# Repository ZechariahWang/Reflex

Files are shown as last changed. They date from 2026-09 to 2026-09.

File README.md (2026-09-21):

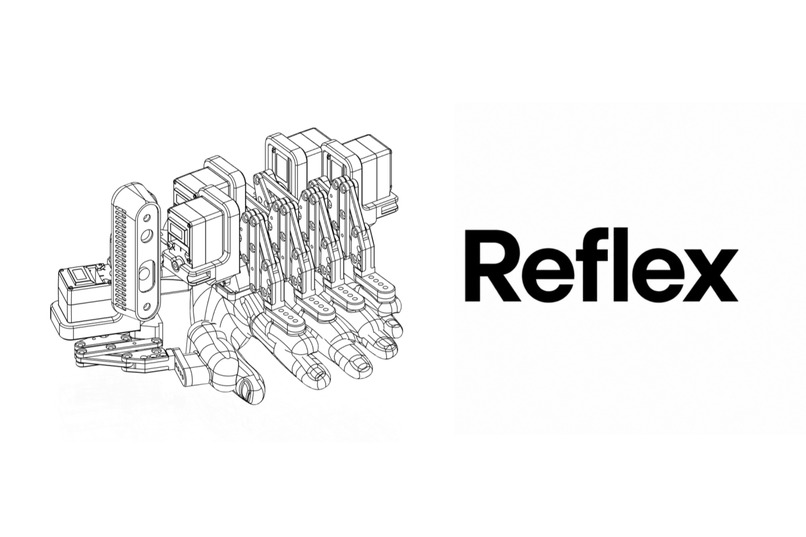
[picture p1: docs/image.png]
Reflex robotic exoskeleton hand


# Reflex

**Hack the North 2026 Finalist | Built in 36 hours**

[Devpost](https://devpost.com/software/reflex-e0jkih) |
[GitHub](https://github.com/ZechariahWang/Reflex)

**Usually, humans write skills for Claude. We wanted a hand where Claude could write skills for humans.**

Reflex is a wearable, 3D-printed gauntlet that gives AI control over five independently
actuated fingers. Built from the ground up at Hack the North 2026, it combines
programmable movements, hand-tracking teleoperation, and a fine-tuned SmolVLA policy
with a live digital twin. The same control interface drives the simulated hand
and the real servos.

The inspiration is hand-over-hand teaching: capture a physical motion, repeat it,
and explore how an AI can help guide it. Reflex is a hackathon prototype, not a
validated rehabilitation device.

Our vision is assistance with dexterous tasks: helping people with limited hand
mobility, guiding someone through a new skill, or supporting hands fatigued by
repetitive work. Those are the applications we want to explore, not established
clinical or workplace outcomes.

## What It Does

- **Agent-controlled movement:** an MCP server lets Claude inspect finger positions,
  command poses, and write, run, or edit named movement sequences.
- **Hand mirroring:** MediaPipe tracks a controller's hand through a webcam and
  translates its motion into finger commands after calibration.
- **Demonstration recording:** record and replay episodes from the console. The
  LeRobot integration connects demonstrations to SmolVLA training and inference.
- **Live digital twin:** a Three.js URDF view shows measured and commanded motion,
  IMU orientation, and tracked objects alongside RGB/depth feeds and motor telemetry.
- **Reusable skills:** rehearsed piano routines and taught movements live as
  readable Python files in [`movements/`](movements/README.md).

## The Piano Demo

One of our favorite demos paired Reflex with Claude to guide someone who had never
played piano through a tune, moving their fingers note by note. Claude runs the
finger routines through MCP while the console shows the commanded and measured
movement. It is a concrete example of the idea behind Reflex: an AI-authored skill
becoming a physical motion a person can experience.

## Built in 36 Hours

Reflex was built from the ground up in 36 hours at Hack the North, with Kevin Zhao,
Zechariah Wang, and Eric Liu. The project was selected as a Hack the North finalist.
See the [Devpost submission](https://devpost.com/software/reflex-e0jkih) for the
project story.

## Architecture

```text
Web console / Claude MCP
           |
     FastAPI backend
           |
        rosbridge <--- LeRobot / learned policy
           |
     ROS 2 hand HAL
       /         \
ros2_control   USB bus adapter
     |               |
   Gazebo       Feetech servos

Camera frames, IMU, and measured state flow back to the console.
```

Commands use five normalized finger positions in **thumb, index, middle, ring,
pinky** order: `0` is open and `1` is closed. Each finger has one controlled degree
of freedom. The HAL applies motion limits and hardware-specific control; agents
and learned policies use that same low-level interface.

## Tech Stack

| Area | Technology |
| --- | --- |
| Hardware | 3D-printed 5-DOF exoskeleton, Feetech STS3215 bus servos, USB servo adapter |
| Sensing | Gauntlet-mounted Intel RealSense D435i RGB/depth/IMU; iPhone + Record3D for an additional overhead or head-mounted view |
| Robot control | ROS 2 Humble, `ros2_control`, Gazebo Fortress, rosbridge |
| Backend | Python, FastAPI, `roslibpy`, OpenCV, MediaPipe |
| Console | Next.js, React, TypeScript, Three.js, React Three Fiber, `urdf-loader`, Zustand, Tailwind, shadcn |
| Agent interface | MCP tools for inspection, movement, and skill creation |
| Learning | LeRobot, SmolVLA, PyTorch |

## Quick Start

### Console Without Hardware

On Linux or WSL, install Python with `venv`, Node.js/npm, and the standard shell
utilities used by the launcher. From the repository root:

```bash
MOCK=1 ./application/dev.sh
```

Open **http://localhost:3000**. The launcher installs backend/frontend dependencies
on first run and starts FastAPI on port `8000` and Next.js on port `3000`.
Mock mode supplies synthetic hand state and camera feeds without ROS or hardware.

See the [console guide](application/README.md) for configuration and the
[API contract](application/CONTRACT.md) for topics and message formats.

### ROS Simulation

With ROS 2 Humble and Gazebo Fortress installed:

```bash
./physical_layer/build.sh
source physical_layer/ros2_ws/install/setup.bash
ros2 launch htn_launch sim.launch.py camera:=none
```

In a second terminal:

```bash
./application/dev.sh
```

Use `gui:=true` for the Gazebo window or `teleop:=false` to skip the finger-control
window. The simulator does not supply synthetic camera images: connect a real
camera for vision workflows, or use console mock mode.

Without a native Humble environment,
[`physical_layer/docker/run.sh`](physical_layer/docker/run.sh) provides a container
with the repository mounted. The host-side
[RealSense bridge](physical_layer/camera_bridge/realsense_bridge.py) can publish
camera data over rosbridge without a local ROS installation.

### Real Hand

After configuring servo IDs, calibration, and the serial device:

```bash
ros2 launch htn_launch hardware.launch.py serial_port:=/dev/ttyACM0
```

Physical dimensions, joint limits, and servo calibration live in
[`hand_params.yaml`](physical_layer/ros2_ws/src/htn_description/config/hand_params.yaml).
Read the [physical-layer notes](physical_layer/CLAUDE.md) before changing hardware settings.

The finger-control window uses `Q W E R T` to open the thumb through pinky and
`A S D F G` to close them. Release a key to hold position. Sliders and preset
gestures are available too. Foxglove can connect at `ws://localhost:8765`; import
the [hand layout](physical_layer/foxglove/htn_hand.json) for robot and camera views.

## Connect Claude

The MCP server is a separate client of the backend. Starting the console does
not automatically register it. On Linux/WSL, from the repository root:

```bash
python3 -m venv mcp_server/.venv
mcp_server/.venv/bin/pip install -r mcp_server/requirements.txt
claude mcp add htn-hand -- "$PWD/mcp_server/.venv/bin/python" "$PWD/mcp_server/server.py"
```

With the backend running, Claude can use `get_hand_state`, `move_hand`,
`list_skills`, `teach_skill`, `run_skill`, and `stop_skill`. For example:
"Read the hand state, then make a peace sign."

See the [MCP guide](mcp_server/README.md) for Claude Desktop, HTTP transport, and
remote backend configuration. MCP commands use the backend directly, so the
console's ARM switch does not gate them. HAL limits still apply; passive mode
disables motor torque and ignores motion commands.

## Learning From Demonstrations

The hand is packaged as a LeRobot robot. For the hackathon, demonstrations were
collected through MediaPipe hand tracking while controlling the simulated hand,
then used to fine-tune SmolVLA for grasp-related finger movements. This let us build
the training workflow without collecting demonstrations by driving a wearer's hand.

The recorded training run used 49 episodes, with 44 for training and five held out,
and completed 5,000 fine-tuning steps. See the
[training run notes](docs/notes/training/runs/RUN-20260920T093202Z/notes.md) for evaluation
results and limitations. The policy runs separately from ROS and communicates
through rosbridge; the RealSense also supplies depth for scene perception in the console.

See the [policy guide](policy/README.md) for Python requirements, dataset collection,
training, and inference commands. Held-out prediction accuracy measures how well
the model matches recorded actions; it does not by itself establish reliable
closed-loop grasping or general skill transfer.

## Repository Map

| Directory | Purpose |
| --- | --- |
| [`physical_layer/`](physical_layer/CLAUDE.md) | Robot description, ROS launch files, HAL, servo backends, teleop, camera bridges, and Docker setup |
| [`application/`](application/README.md) | FastAPI backend and live web console |
| [`mcp_server/`](mcp_server/README.md) | Claude-compatible hand-control and skill-management tools |
| [`movements/`](movements/README.md) | Rehearsed and agent-taught finger routines |
| [`policy/`](policy/README.md) | LeRobot integration, recording, training, and inference tooling |
| [`docs/`](docs/) | Designs, development notes, and demo instructions |

## What's Next

- Finish compliant, torque-on hand-guiding control. Existing torque-off backdrive
  mode is distinct from a tuned, soft hand-guiding controller.
- Expand the demonstration dataset and evaluate learned skills beyond their
  training examples.
- Explore how recorded motions and agent-authored skills can support physical
  skill practice and assistive tasks.

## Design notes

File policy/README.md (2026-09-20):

# policy

LeRobot side of the learned policy. Everything here runs on the GPU laptop and
reaches the hand through the rosbridge websocket of the ROS machine
(`ws://<ros-ip>:9090`). Design: `../docs/specs/policy-link-design.md`.

`lerobot_robot_exo_hand` is the hand as a LeRobot `Robot` (`--robot.type=exo_hand`).

## Setup

Python >= 3.12 (a requirement of `lerobot`). No ROS.

```bash
cd policy
uv venv --python 3.12 && source .venv/bin/activate
uv pip install -e ".[dev]" "lerobot[smolvla,async,training]==0.6.1"   # async = gRPC for the inference loop, training = lerobot-train
python -m pytest            # no rosbridge needed
```

## Smoke check

With `sim.launch.py` or `hardware.launch.py` running on the ROS machine and the
camera plugged in (the sim has no simulated camera):

```bash
python -m lerobot_robot_exo_hand.exo_hand --host <ros-ip>
```

It prints one observation (the state and the shapes of `camera1`, the head
iPhone, and `camera2`, the wrist RealSense), closes the hand, opens it again, and
fails if `/hand/state` does not follow. With no phone: `--head-topic ""`, and
`--robot.head_topic=""` in the commands below.

## The instruction

One constant string, in every episode and at inference, character for character:

    grasp and put down objects, make a peace sign at a person

It is the default of the console's Task field. The model sees the same words in every sample, so
they tell it nothing: WHICH of the two it does, and when, it learns from the cameras in the
episodes. A different string at inference is an input it was never trained on. So the data has to
tell the two apart:

- grasp episodes with people in the background (or every person in view means "peace sign");
- peace sign episodes with one clear cue: the hand up, palm away, a person close and centred;
- idle episodes: a person in view, or an object out of reach, and the hand does nothing;
- every grasp episode is the whole cycle: approach, grasp, hold, put down, release;
- about as many episodes of the one as of the other.

## Data collection: mirror teleop (torque on)

Design: `../docs/specs/mirror-teleop-design.md`. A second person (the controller)
closes a hand in front of a browser webcam, the web console turns it into
`/hand/command`, and the hand moves with the torque on. `exo_hand_command` records
the last `/hand/command` as the action (the measured `/hand/state` until the first
command); the observation state is `/hand/state`. It works with any command source
(mirror, sliders, keys), and refuses a HAL in passive mode. `--robot.passive=true`
stops the robot from publishing each command a second time. No `label.py` step.

In the web console: ARM, Mirror on, calibrate (open hand, fist), match the hand
until the mode is `following`. Nobody arms the sliders in another tab. Then:

```bash
lerobot-record \
    --robot.type=exo_hand --robot.host=<ros-ip> --robot.id=exo --robot.passive=true \
    --teleop.type=exo_hand_command --teleop.host=<ros-ip> --teleop.id=exo \
    --dataset.repo_id=<user>/exo_grasp --dataset.push_to_hub=false \
    --dataset.root=policy/datasets/exo_grasp \
    --dataset.single_task="grasp and put down objects, make a peace sign at a person" \
    --dataset.fps=30 --dataset.num_episodes=50 \
    --dataset.episode_time_s=20 --dataset.reset_time_s=5
```

Right arrow = save the episode, left arrow = record it again, Esc = stop (the keys
may not work on Wayland; `episode_time_s` is the upper limit then).

## Data collection from the web console

The Episodes bar of the console (under the 3D hand) records without LeRobot on the ROS machine:
type a dataset name and the task, **Record**, move the hand (mirror, sliders, keys), **Save** or
**Discard**; **Replay** plays an episode back on the hand and in the camera panels. The episodes are
in `policy/datasets/console/<name>/` in the console's own format
(`application/CONTRACT.md`, Episodes). On the machine that trains:

```bash
python -m lerobot_robot_exo_hand.from_console --root policy/datasets/console/exo_grasp
```

writes `policy/datasets/exo_grasp`, a LeRobot dataset with the same columns as `lerobot-record`
below (`observation.state`, `action` = the last command, `camera1`, `camera2`). Not run against
lerobot yet when it was written: check the first conversion with `lerobot-dataset-viz` or the
replay below.

## Replay of a LeRobot dataset

```bash
python -m lerobot_robot_exo_hand.replay --root policy/datasets/exo_grasp --episode 0 --host <ros-ip>
```

Plays one episode back through rosbridge at the fps it was recorded with: `action` goes to
`/hand/command` (the hand of the sim, or the real one, does what it was told), and the two camera
images go to `/head_camera/color/image_raw/compressed` and `/camera/color/image_raw/compressed`,
so the web console and Foxglove show what the cameras saw next to the moving hand. For that the ROS
side must have NO camera of its own running: `ros2 launch htn_launch sim.launch.py camera:=none`.
With a live camera pass `--no-images` (the hand only). `--what state` sends the measured
`observation.state` instead of the action (what the hand did, not what it was told),
`--speed 0.5` is half speed, `--loop` repeats until Ctrl-C. It commands the hand: on the real one,
clear its surroundings first. The episode is decoded before the first frame goes out, so a slow
video decode is not part of the timing.

## Data collection: backdrive (closed for these servos)

Design: `../docs/specs/data-collection-design.md`. The HAL is in its torque-off
mode, a person moves the fingers, and the encoder positions are the actions.
`exo_hand_leader` reads them from `/hand/state`; `--robot.passive=true` stops
the adapter from publishing them as commands.

First put the HAL in that mode, on the ROS machine: start it with
`ros2 launch htn_launch hardware.launch.py passive:=true`, or switch a running
one with the Backdrive button of the control window / web console, or
`ros2 service call /hand/set_passive std_srvs/srv/SetBool '{data: true}'`.
`/hand/passive` (latched Bool) tells which mode it is in. With the torque on the
fingers do not move and every label is constant, so `exo_hand_leader` refuses to
record unless `/hand/passive` is true (`--teleop.require_passive=false` for a
recording where something else commands the hand). Afterwards switch it off the
same way (`data: false`): the hand then holds the pose the fingers are in.

Then run from the repo root:

```bash
lerobot-record \
    --robot.type=exo_hand --robot.host=<ros-ip> --robot.id=exo --robot.passive=true \
    --teleop.type=exo_hand_leader --teleop.host=<ros-ip> --teleop.id=exo \
    --dataset.repo_id=<user>/exo_grasp_raw --dataset.push_to_hub=false \
    --dataset.root=policy/datasets/exo_grasp_raw \
    --dataset.single_task="grasp and put down objects, make a peace sign at a person" \
    --dataset.fps=15 --dataset.num_episodes=50 \
    --dataset.episode_time_s=20 --dataset.reset_time_s=5

python -m lerobot_robot_exo_hand.label --root=policy/datasets/exo_grasp_raw --k=3 --gain=0.2
```

The second command writes `policy/datasets/exo_grasp_raw_k3_g20`, the dataset
to train on: `action[t] = min(1, state[t+k] * (1 + gain))`. The raw dataset
does not change, so `k` and `gain` can change with no new recording.

`policy/datasets/` is ignored by git and is not a cache: make a copy outside
the repo after each session.

## Training

`lerobot-train` does it; there is no training code of ours. A rental of a Lambda GPU runs it
with no person at the keyboard (next section). By hand, on a machine with a GPU: the Setup
above, then

```bash
lerobot-train \
    --policy.path=lerobot/smolvla_base --policy.device=cuda --policy.push_to_hub=false \
    --dataset.repo_id=<user>/exo_grasp_raw_k3_g20 --dataset.root=<path>/exo_grasp_raw_k3_g20 \
    --batch_size=64 --steps=20000 --save_freq=5000 \
    --output_dir=outputs/train/exo_grasp --wandb.enable=false
```

The checkpoint for the inference loop is
`outputs/train/exo_grasp/checkpoints/last/pretrained_model` (~1.3 GB with the
training state). Copy it off a cloud instance before termination.

Checked on 2026-09-19 with a dry run on a CPU (10 steps, batch 2, the
150-frame test recording): the 5-value state and action need no option and no
model change, the loss goes down, and the checkpoint gives a `(1, 5)` action
from a 5-value state and one `camera2` image. `batch_size`, `steps` and the
`cuda` device are not run. The checkpoint keeps the input list of
`smolvla_base` in its `config.json` (a 6-value state, `camera1`..`camera3`);
the model pads the state to 32 values and skips the cameras that are not
there, so this had no effect in the dry run.

If the log says that `torchcodec` cannot load `libavutil`, lerobot decodes the
video with `pyav`. It works, and it is slower: install an FFmpeg that
`torchcodec` supports on the training machine.

## Training on a rented Lambda GPU

Design: `../docs/specs/lambda-training-design.md`. `lambda/launch.sh` rents one instance, uploads
`policy/`, one dataset, the `exo-trainer` skill and `docs/notes/training/`, and starts Claude Code
(Fable 5.1) there. The agent runs the variants of `docs/notes/training/plan.md`, evaluates each
checkpoint on held-out episodes (`heldout.py`), writes `docs/notes/training/runs/RUN-<UTC>/` and
ends the rental. `lambda/watchdog.sh` on the laptop pulls `policy/outputs/`, `policy/logs/` and the
run notes every 5 minutes and terminates the instance: 30 minutes after the last sign of life, at
`LAMBDA_MAX_HOURS`, or when the agent asks. **Keep the laptop awake and online for the whole
rental: nothing else stops the billing.**

```bash
cp policy/lambda/.env.example policy/lambda/.env   # the keys, the GPU type, LAMBDA_DATASET, the cap
policy/lambda/check_key.sh
policy/lambda/launch.sh --dry-run          # the confirm screen and the capacity, no launch
policy/lambda/launch.sh --smoke-scripts    # ~10 min, no agent: 50 steps on a fake dataset
policy/lambda/launch.sh --smoke            # the agent, two 50-step variants on the fake dataset
policy/lambda/launch.sh                    # the rental of plan.md; then: tmux attach -t htn-train
policy/lambda/check_instance.sh            # what bills now
policy/lambda/terminate.sh                 # stop it by hand
```

A smoke run is good if a `pretrained_model` folder and a `results.jsonl` are on the laptop and
`check_instance.sh` shows no instance. Several recording sessions: merge them into one dataset
before a rental. Delete an episode only with `lerobot-edit-dataset`, never by hand: it numbers the
episodes again. The checkpoints come home without `training_state/` (~1 GB each), so a run does not
resume on another rental. Revoke the `claude setup-token` token after the hackathon.

Tests of the scripts, with no instance and no key:

```bash
for t in policy/lambda/tests/test_*.sh; do bash "$t"; done
```

## Inference loop

Two processes on the GPU laptop. The server stays on localhost; only rosbridge
crosses the network. The ROS side runs first: rosbridge, the two cameras, the HAL.

```bash
cp .env.example .env     # once: POLICY_CHECKPOINT = the pretrained_model folder of a checkpoint, ROS_HOST
./run_policy.sh          # the policy server, then the robot client. Ctrl+C stops both
```

`run_policy.sh` refuses a checkpoint folder with no `model.safetensors` and a `POLICY_PORT` that is
already in use (any listener there passes the wait for the server, and the client then talks to the
wrong one), drops the `PYTHONPATH` of a shell that has sourced ROS (its Python 3.10 packages break the
import of lerobot), and gives the client the instruction above. With no phone on the forehead,
`POLICY_HEAD_TOPIC=` (set, and empty) in `.env` runs on the wrist camera only: a model that was
trained with both cameras does worse like that. The hand does not move yet: the policy waits for the **Policy** switch of the web
console (command block, armed). The switch is the latched `/policy/enabled`; while it is off the
adapter drops every action, and the step to off opens the hand once. `/policy/active` is the
heartbeat that the console shows as offline / ready / running. `POLICY_GATE=0` in `.env` is a run
with no console: the policy moves the hand from its first action. The switch is a convenience, not
an emergency stop: that is Ctrl+C here, and the limits of the HAL. The same by hand, in two terminals:

```bash
python -m lerobot.async_inference.policy_server --port=8080

python -m lerobot.async_inference.robot_client \
    --robot.type=exo_hand --robot.host=<ros-ip> --robot.id=exo \
    --server_address=localhost:8080 \
    --policy_type=smolvla --pretrained_name_or_path=<checkpoint> \
    --policy_device=cuda \
    --task="grasp and put down objects, make a peace sign at a person" \
    --fps=30 --actions_per_chunk=20 --chunk_size_threshold=0.7 \
    --debug_visualize_queue_size=True
```

Measured on the RTX 4050 laptop (2026-09-20, the 3000-step checkpoint): an inference takes 0.15 .. 1.2 s.
`POLICY_ACTIONS_PER_CHUNK` times the tick must be longer than that, or the hand waits between chunks:
20 actions are 0.67 s at 30 fps, too short there; 50 (the whole chunk of the model, 1.67 s) is not.

A client that dies without closing its websocket leaves rosbridge queueing camera images for it:
its memory grew ~3 MB/s, every client saw gaps of up to 0.7 s, and the robot client logged `no data
from rosbridge within 0.3 s`. Seen once, after two such clients; a fresh rosbridge cured it.

`--fps` (`POLICY_FPS`) is the rate of `send_action()`, and it is the tick rate of the dataset: 30
for a dataset of the web console, the `--dataset.fps` of a `lerobot-record` one. One action of the
model is one tick, so a lower rate plays every movement too slowly. The cameras deliver 15 fps: two
ticks see the same picture, as in the recording. The HAL must
be active: `ExoHand` raises if it is passive, because a passive HAL ignores
every command. To stop the
policy and take the hand back with teleop, stop the client: a running policy
overrides every other publisher on `/hand/command`.

The client of lerobot 0.6.1 has no `rename_map` option, and the server replaces
the map of the checkpoint with an empty one. The adapter therefore names its
camera `camera2`, an image key of `smolvla_base`, and no map is used anywhere.

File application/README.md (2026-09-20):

# application/ - hand simulator console

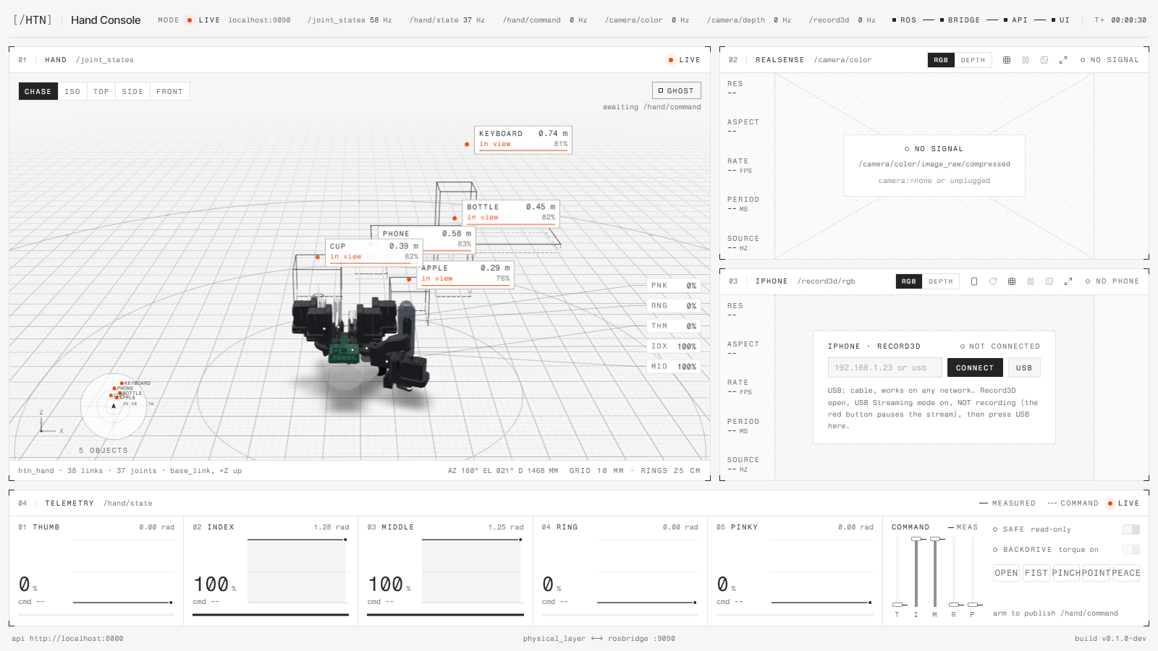
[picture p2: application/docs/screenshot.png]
Hand Console


A one-screen web console for the exoskeleton hand: a three.js viewport of the hand
moving live with a map of the objects around it (detected in the wrist camera, placed with its
depth, faded out when they are not detected any more), a RealSense panel that switches between RGB and
colorized depth, an iPhone (head camera) panel,
and an ARM-gated command block. It only consumes ROS topics from `physical_layer/`,
so it looks the same for the Gazebo sim and the real hardware.
```
physical_layer (ROS 2) --rosbridge ws :9090--> backend (FastAPI :8000) --ws/http--> frontend (Next.js :3000)
```

- `backend/`  - FastAPI + roslibpy. The only thing that talks to ROS. Caches the latest
  value of every topic, colorizes depth, serves `/api/health`, `/api/urdf`, `/ws/state`,
  `/ws/camera/realsense/{color,depth}`, `/ws/camera/iphone/color`. Reconnects to rosbridge forever.
  The iPhone is a ROS camera too (`/head_camera`, started with `head_camera:=iphone`).
- `frontend/` - Next.js, Tailwind, shadcn/ui, motion, three.js (@react-three/fiber, urdf-loader).
- `CONTRACT.md` - every API shape, topic and design rule. Read it before changing either side.

## Run

```bash
# terminal 1 - the ROS side (starts rosbridge on :9090; hardware.launch.py works the same)
ros2 launch htn_launch sim.launch.py

# terminal 2 - backend + frontend, Ctrl-C stops both
./dev.sh                # then open http://localhost:3000
MOCK=1 ./dev.sh         # no ROS at all: synthetic hand, color and depth
```

`dev.sh` creates `backend/.venv` and `frontend/node_modules` on first run. The object
detector is optional: `backend/.venv/bin/pip install -r backend/requirements-detect.txt
--extra-index-url https://download.pytorch.org/whl/cpu` (CPU torch, ~300 MB); without it the
map stays empty in live mode and the backend says so once. Start order does
not matter: with ROS down the console shows OFFLINE / NO SIGNAL and recovers on its own.

| env | default | |
|---|---|---|
| `MOCK` | `0` | `1` = synthesize everything |
| `MOCK_OBJECTS` | `0` | `1` = live ROS, synthetic objects around the hand (a sim has no camera) |
| `REALSENSE_ROTATION` | `270` | degrees clockwise the RealSense picture is turned on the page and for the object detector (the camera sits portrait on the hand); `0` = as sent |
| `DETECT_MODEL` | `yolov8n.pt` | Ultralytics model that finds the objects around the hand in the RealSense image; needs `backend/requirements-detect.txt`, `""` turns it off |
| `DETECT_HZ` / `DETECT_THREADS` | `4` / `2` | detector passes per second at most, and its torch threads (it shares the CPU with the sim and the browser) |
| `ROSBRIDGE_HOST` / `ROSBRIDGE_PORT` | `localhost` / `9090` | where rosbridge listens |
| `BACKEND_PORT` / `FRONTEND_PORT` | `8000` / `3000` | dev.sh ports |
| `BACKEND_HOST` | `127.0.0.1` | dev.sh bind address of the API; `0.0.0.0` from a container or for another machine |
| `DEPTH_MIN_MM` / `DEPTH_MAX_MM` | `150` / `2000` | depth colormap range |
| `CORS_ORIGINS` | `http://localhost:3000,http://127.0.0.1:3000` | pages allowed to call the API and open its websockets |

Viewing from another machine needs `CORS_ORIGINS=http://<host>:3000`, `NEXT_PUBLIC_BACKEND_URL=http://<host>:8000`
and `BACKEND_HOST=0.0.0.0`.

Commands only leave the page while the ARM switch is on; it disarms itself when ROS drops.

Checks: `backend/.venv/bin/pytest` (needs `requirements-dev.txt`); in `frontend/`: `npx tsc --noEmit && npx eslint . && npm run build`.

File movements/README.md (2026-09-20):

# movements

Pre-written movements of the hand, played from the web console (Episodes bar -> the Movement
dropdown -> Play). One Python file = one movement; the backend lists every `*.py` here whose name
does not start with `_`. Add a file, reload the page, it is in the dropdown.

A movement file has:

```python
TITLE = "Hot cross buns"             # the name in the dropdown
DESCRIPTION = "one line, optional"

def steps():
    """The movement: a list of (pose, seconds). The pose is sent to /hand/command; the next one
    is sent when `seconds` have passed AND the hand has arrived at this one. A pose is 5 values
    in the order thumb, index, middle, ring, pinky, 0 = open .. 1 = closed."""
    return [([0, 0, 0, 0, 0], 0.5), ([0, 1, 1, 0, 0], 1.0)]
```

A step never starts before the last one has arrived: every finger measured within 0.04 of the
pose that was sent. So `seconds` is the shortest a step takes, and slow motors stretch the tempo
instead of cutting strokes short. A finger that cannot arrive (something is in its way, the torque
is off) holds the movement for 3 s, then it goes on; the status counts those steps (`not_arrived`).

Rules the backend checks: at most 2000 steps, each 0 < seconds <= 30, values are clamped to 0..1.
The HAL still rate-limits every move (`max_speed` 4.0 of the travel per second: a full close takes ~0.3 s, a stroke of depth d about d / 4 + 0.07 s) and the contact stop
still applies: a movement cannot go faster or push harder than a slider can. A movement can play
while an episode is being recorded (that is a way to record demonstrations), not during a replay.

Try one without the console: `python3 movements/hot_cross_buns.py` prints its steps.

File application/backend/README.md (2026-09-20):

# backend

FastAPI bridge between rosbridge (`ws://localhost:9090`) and the browser. API: `../CONTRACT.md`.

```bash
python3 -m venv .venv && .venv/bin/pip install -r requirements-dev.txt   # setup
.venv/bin/uvicorn app.main:app --port 8000                               # run (ROS may be down; it reconnects forever)
MOCK=1 .venv/bin/uvicorn app.main:app --port 8000                        # mock mode: no ROS, synthetic hand + cameras
.venv/bin/python -m pytest -q                                            # tests
```

Env: `ROSBRIDGE_HOST` (localhost), `ROSBRIDGE_PORT` (9090), `MOCK` (0), `CORS_ORIGINS` (http://localhost:3000,http://127.0.0.1:3000;
comma-separated), `DEPTH_MIN_MM` (150), `DEPTH_MAX_MM` (2000), `MIRROR_*` (mirror teleop tuning, see `../CONTRACT.md`).

iPhone: a ROS camera like the RealSense (`/head_camera/color/image_raw/compressed`, from `camera.launch.py head_camera:=iphone`);
the backend passes its JPEGs through. The phone itself (Record3D, USB) belongs to the ROS node. No phone around? `MOCK=1`.

Mirror teleop: `app/mirror/` tracks the controller's webcam frames from `/ws/mirror` with MediaPipe (`models/hand_landmarker.task`, Google's
pretrained float16 model, in the repo so nothing downloads at run time). The pinned numpy needs Python <= 3.13 for the venv.

`mock/hand.urdf` is generated from `htn_description/urdf/hand.urdf.xacro`; regenerate it if the xacro changes.

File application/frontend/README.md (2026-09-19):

# frontend - HTN hand console

Next.js (App Router) + Tailwind v4 + shadcn/ui + motion + three.js (`@react-three/fiber`, `drei`, `urdf-loader`).
One screen: hand viewport, color + depth camera views, telemetry strip. Architecture and API: `../CONTRACT.md`.

```bash
cp .env.example .env.local   # NEXT_PUBLIC_BACKEND_URL, default http://localhost:8000
npm install
npm run dev                  # http://localhost:3000 (start ../backend first; MOCK=1 needs no ROS)
```

Shared code: `src/lib/{config,types,sim-store}.ts`, `src/hooks/use-camera-stream.ts`, `src/components/console/panel.tsx`; design tokens and the `label-micro` / `num` / `hairline-frame` / `bg-dot-grid` utilities live in `src/app/globals.css`.

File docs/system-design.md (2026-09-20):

# System design

Device layout, ROS layout and learned finger control for the exoskeleton hand.
Status: design only, the autonomous part is not implemented. Date of the
discussion: 2026-09-19.

## Device layout

```
        on the wearer                                  on a table
+--------------------------------+            +---------------------------+
| hand                           |            | GPU laptop (8 GB VRAM)    |
|   servos <- USB-C motor driver |            |   LeRobot policy_server   |
|   wrist camera (RGB + depth)   |            |   SmolVLA                 |
|        | USB          | USB    |            |   RobotClient + ExoHand   |
| wearable ROS machine           |  5 GHz     |   no ROS                  |
|   (Pi 5 or small laptop)       |  WiFi      |                           |
|   ROS 2 Humble, rosbridge      | <--ws:9090-|                           |
+--------------------------------+            +---------------------------+
```

- **Hand:** 5 servos behind a USB-C motor driver, and a wrist camera with depth.
  Both connect to the wearable machine over USB.
- **Wearable ROS machine:** runs all ROS nodes. The wearer carries it. It has
  no GPU work, no `lerobot` and no torch.
- **GPU laptop:** runs all the LeRobot parts: `policy_server`, `RobotClient`
  and the `ExoHand` adapter (`lerobot-record` also, during data collection).
  It stays off the body. It needs no ROS, only `roslibpy`.
- **Link:** 5 GHz WiFi hotspot. Bluetooth is too slow for video. An Ethernet
  cable is an option only when the wearer does not move around.
- **Viewing:** a third device can open Foxglove on
  `ws://<wearable-ip>:8765`. It needs no ROS.

Only the rosbridge WebSocket (JSON: `/hand/state`, JPEG frames in, and
`/hand/command` out) and the Foxglove WebSocket cross the network. No DDS
traffic crosses it, so the ROS 2 over WiFi problems (multicast discovery,
fragmented image messages) do not apply. gRPC between `RobotClient` and
`policy_server` stays on localhost of the GPU laptop. See
`specs/policy-link-design.md`.

rosbridge has no authentication: any device on the network can publish
`/hand/command`. Use an own router, a hotspot or a cable, not the venue WiFi.

## ROS layout (wearable machine)

```
camera node --/camera/... images--+
                                  v
                             rosbridge  <--ws:9090-->  ExoHand adapter (GPU laptop)
                                  |  ^
                   /hand/command  v  |  /hand/state
teleop_gui --/hand/command-->    HAL  --USB--> motor driver --> servos
                                  |
                                  +--/hand/state, /joint_states--> foxglove_bridge
```

- `hardware.launch.py` starts `robot_state_publisher`, the HAL (feetech
  backend), `teleop_gui`, the camera node, `foxglove_bridge` and
  `rosbridge_websocket`. The policy link adds no node to this machine.
- The contract does not change: anything that moves the hand publishes
  `/hand/command` (5 values, `0` = open, `1` = closed) and reads `/hand/state`.
  The policy is one more publisher, the same as teleop. The topic is shared
  and the last message wins, so a publisher sends only when it has something
  new; the policy adapter has a deadband for this.
- The HAL clamps and rate-limits (`max_speed`) each command before it reaches
  the servos. This stays below the policy.
- The image topics are also the source for dataset recording and for Foxglove,
  so video and `/hand/state` have timestamps from one clock.

### Wearable machine: Pi 5 or small laptop

| | Pi 5 | Small x86 laptop |
|---|---|---|
| ROS 2 Humble | Needs a container. Ubuntu 22.04 does not boot on a Pi 5. Use distrobox with `ubuntu:22.04` on Raspberry Pi OS or Ubuntu 24.04. | Native, or the same distrobox setup as the dev machine |
| Device access in distrobox | Create the box with `--additional-flags "--group-add keep-groups"` (or `--root`) for `/dev/ttyACM0` and the camera | Same |
| Teleop window | `teleop_gui` needs a display and a keyboard | Built in |
| Power | 5 V / 5 A supply, plus 1-2 W for the camera | Own battery |
| Video encode | No hardware encoder; the `/compressed` topics are JPEG on the CPU, and rosbridge adds base64 per client. Measure the load early. | - |

Start at boot on a Pi: a systemd service that runs
`distrobox enter humble -- <launch command>`. Test it early.

## Policy

**SmolVLA** (0.45B parameters, Apache 2.0, part of
[LeRobot](https://github.com/huggingface/lerobot)), fine-tuned with one constant
instruction.

- **Task:** close when the wearer reaches for an object, hold during transport,
  release when the wearer puts the object down. The wearer cannot move their
  fingers. The servos cannot be backdriven: a torque-off mode exists in the HAL,
  but the gear friction makes the fingers too stiff to move by hand
  (`specs/data-collection-design.md`, Backdrive result).
- **Input:** wrist RGB and depth, and the 5 values of `/hand/state`.
  **Output:** 5 targets for `/hand/command`.
- Inference needs ~2 GB of VRAM. The constant instruction makes the language
  input irrelevant; the reason to use a VLA is the pretrained vision.
- Fallback if SmolVLA generalizes poorly: GR00T N1.6. π0 and π0.5 do not fit.

| Model | Inference VRAM | Fine-tune VRAM |
|---|---|---|
| SmolVLA | ~2 GB | 10-24 GB |
| GR00T N1.6 | ~6 GB | 24 GB+ |
| π0 / π0.5 | 8 GB+ | 22.5 GB+ (LoRA) |

### Inputs

- State and action have 5 values each. SmolVLA pads them to its internal size.
- `smolvla_base` declares three image slots, `observation.images.camera1`,
  `camera2`, `camera3` (top, wrist, side in the pretraining data). Map the
  dataset keys to the slots with `--rename_map`, and mask unused slots with
  `--policy.empty_cameras=N`. Put the wrist RGB in `camera2`.
- Async inference in lerobot 0.6.1 ignores `rename_map`, so the adapter names
  its camera `camera2` directly and no map is used, see
  `specs/policy-link-design.md`.
- **Depth:** record it as a second video stream (color map) and map it to a
  camera slot. The vision encoder has not seen depth images, so unfreeze it for
  that run (`freeze_vision_encoder=false`, `train_expert_only=false`). Option if
  depth does not help as an image: add the median center depth to the state
  vector.

### Inference link

Uses [LeRobot asynchronous inference](https://huggingface.co/docs/lerobot/en/async).
The server computes the next chunk of actions while the client executes the
current one.

- GPU laptop:
  `python -m lerobot.async_inference.policy_server --host=0.0.0.0 --port=8080`.
  The server starts empty; the client names the policy and the checkpoint at
  the first connection.
- Also on the GPU laptop: a `RobotClient` that wraps one small LeRobot `Robot`
  subclass for the hand (`ExoHand`). It reaches the ROS topics through
  rosbridge with `roslibpy`. `get_observation()` returns the latest frame and
  `/hand/state`; `send_action()` publishes to `/hand/command`. The action
  queue is thus off the robot: each command crosses WiFi.
- `lerobot-record` uses the same `Robot` class, so recording and inference
  share keys and camera order.
- Start with `actions_per_chunk` = 10-20 and `chunk_size_threshold` = 0.7 for a
  short reaction time. Check the queue with `--debug_visualize_queue_size=True`.

| Step | Time |
|---|---|
| WiFi, one direction | 2-10 ms, spikes to 50 ms or more |
| Frame age at `get_observation()` | up to 66 ms at 15 fps, plus transit |
| SmolVLA inference | 100-200 ms |

## Training

- Cloud GPU on Lambda. An A10 (24 GB) is sufficient for the default fine-tune;
  use an A100 for the run with the unfrozen vision encoder.
- How a rental runs (launch, watchdog on the laptop, agent on the instance,
  held-out evaluation): `specs/lambda-training-design.md`.
- Lambda deletes the instance storage at termination. The watchdog on the
  laptop pulls the checkpoints with `rsync`; nothing goes to Hugging Face.
- Dataset storage: local files only. The dataset contains video of people; it
  goes from the laptop to the instance by `rsync` and nowhere else.
- 20,000 steps take ~4 hours on an A100.
- Train three versions and compare them on held-out objects:
  1. RGB only, frozen vision encoder (default)
  2. RGB and depth, frozen
  3. RGB and depth, unfrozen

## Safety

These stay in the HAL, below the policy and the network. The motor driver has
no firmware of ours, so the HAL is the lowest layer that we control:

- Clamp and rate limit (exists in the HAL).
- Hard limit on force or current.
- Link loss: the HAL keeps the last target with no time limit, so the hand
  finishes its last commanded move and holds. Hold is the chosen action (an
  open drops the object at each WiFi dropout), so the HAL needs no watchdog.
  The adapter stops the client when its data is old.
- An emergency open that the wearer can always reach.

## Open questions

1. **Where the `RobotClient` runs.** Closed, see
   `specs/policy-link-design.md`: on the GPU laptop, through rosbridge. No
   process imports both `rclpy` and `lerobot`, and `htn_auto` is removed.
2. **Depth camera model.** The object is 5-20 cm from a wrist camera at the
   moment of the grasp. A RealSense D435 cannot measure below ~28 cm; a D405
   operates from ~7 cm. On a Pi, `librealsense` needs a source build.
3. **Release signal.** A learned release is a risk (dropped object or trapped
   hand). Recommended for the first version: learned close, explicit release
   input from the wearer (button, voice, or IMU gesture).
4. **Wearable machine.** Pi 5 or small laptop, see the table above.
5. **Wrist IMU.** It gives the "arm stopped" cue directly and helps most with
   the release.
6. **Motor driver protocol.** Closed, see `specs/feetech-hal-design.md`: Feetech ST
   servos on a USB bus adapter, position feedback, no command timeout. Original question: The `SerialBackend` in the HAL speaks an ASCII
   protocol (`S ...` / `P ...` lines) made for our own firmware. A driver board
   has its own protocol, so the HAL needs a backend for it. Check also whether
   the driver has a command timeout and position feedback; if it has no
   timeout, the watchdog must be in the HAL.
7. **Command arbitration.** `/hand/command` is shared and the last message
   wins. A policy that streams at 15-30 Hz overrides teleop and the web
   console while it runs; the only takeover is to stop the client.

## Alternatives considered

- **Pi with no ROS** (MJPEG stream plus the serial port over TCP, all ROS on
  the GPU machine). Simplest, but it puts ROS and the GPU on one machine.
- **ROS nodes on two machines.** ROS 2 over WiFi is unreliable (discovery,
  large messages).
- **`RobotClient` on the wearable machine** (gRPC across WiFi, the action
  queue on the robot). The queue drains through a short dropout, but
  `lerobot` and torch go onto the wearable machine, and one process needs
  both `rclpy` (Python 3.10) and `lerobot`.
- **One laptop for everything.** Rejected: the wearer must not carry the GPU.
- **ACT.** Not used, also not as a baseline: it has no pretrained vision, and
  SmolVLA is the only model that is trained.

## Links

- [LeRobot repository](https://github.com/huggingface/lerobot)
- [Async inference docs](https://huggingface.co/docs/lerobot/en/async),
  [source](https://github.com/huggingface/lerobot/tree/main/src/lerobot/async_inference)
- [SmolVLA docs](https://huggingface.co/docs/lerobot/en/smolvla),
  [base weights](https://huggingface.co/lerobot/smolvla_base)
- [Rename map and empty cameras](https://huggingface.co/docs/lerobot/rename_map)
- [rosbridge protocol](https://github.com/RobotWebTools/rosbridge_suite/blob/ros2/ROSBRIDGE_PROTOCOL.md),
  [roslibpy](https://roslibpy.readthedocs.io/)
- [ACT paper](https://arxiv.org/abs/2304.13705)

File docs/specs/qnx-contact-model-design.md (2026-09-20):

# QNX track: a learned contact detector on a Raspberry Pi

Status: proposal from the discussion of 2026-09-20. Nothing is built and nothing here is tested
on QNX. The open questions at the end are not decided.

## The track

Hard requirements: the project uses QNX OS, and it includes one of the open-source AI modules
of https://oss.qnx.com. Judging: is it a "cannot-fail" embedded application, does it need
real time or reliability, is the AI use interesting, and does it run on the embedded hardware
or a QNX VM (not in the cloud).

The SmolVLA policy runs on the GPU laptop, so it does not count. Something with AI has to run
on the QNX machine itself.

## The idea

A Raspberry Pi 4 with QNX 8.0 runs a small model that says, per finger, "this finger meets
resistance". It is a learned version of the contact stop in `hal/contact.py`.

Why this and not a vision model: the contact stop IS the safety decision of the hand (it
protects the linkage and the wearer's fingers, and it sets the grip force), it needs the 50 Hz
loop, and it must keep working when the laptop or the policy dies. That is the story the judges
ask for.

### What the model can do better than the threshold

The detector of today sums the motor current above `blocked_current` (100 mA) and blocks at
`blocked_excess` (100). One threshold for every position and speed:

- a free start of the middle finger already summed to 34;
- near a linkage bind the leverage changes, so the current for the same force depends on where
  the finger is (ring and pinky are within a few degrees of a bind, `next-work.md`);
- it cannot be early: it waits for the sum.

A model that sees position and velocity next to the current can learn both.

### Model

- Input: the last ~10 HAL cycles (0.2 s) of one finger: current (mA), position, velocity, push
  direction. One model for all five fingers, run once per finger.
- Output: probability of contact.
- A small 1D-CNN or MLP: far below 1 ms on a Pi 4.
- Trained on the laptop (Keras), converted to `.tflite`, run on QNX with
  `python3-tflite-runtime`.

### Safety rule

`blocked = threshold detector OR model`. The model can only stop a finger earlier; it can never
cancel a stop of the threshold. Torque limits, clamps and the threshold stay hard-coded below
it ("Safety limits ... belong in the HAL and the servo registers, below any learned policy").

## Two ways to build it

1. **Advisory (no hardware risk).** The HAL stays on the laptop. A relay node (~30 lines) sends
   `/hand/current`, `/hand/state` and `/hand/command` to the Pi on UDP, the Pi sends the model's
   verdict back, the console shows it next to `/hand/blocked`. The verdict does NOT stop the
   hand: a network link in the safety path is worse than what there is now. Qualifies, but the
   Pi is a side process and a judge can see that.
2. **The HAL on the Pi (the full story).** The Pi owns the servo bus and runs the 50 Hz loop,
   the threshold, the model and a watchdog that holds the pose when the laptop goes silent. The
   laptop only sends `/hand/command`. `hal/` is ~430 lines and needs only `rclpy`, `std_msgs`,
   `std_srvs`, `sensor_msgs` and `pyserial`.

Recommended order: 1 first, then 2 if the USB adapter test below passes.

## What is on oss.qnx.com

From the dashboard's API (`/packages?package_name=...&arch_id=aarch64&latest_only=1` on the
`API_URL` in the page source), 2026-09-20. Prebuilt `apk` packages unless noted; targets are
Raspberry Pi 4 and 5.

| Module | Packages | QNX | Python |
|---|---|---|---|
| TensorFlow Lite | `tflite-runtime`, `python3-tflite-runtime` 2.21.0 | 8.0.3 | yes |
| MediaPipe | `mediapipe`, `python3-mediapipe-cpu` 0.10.26 | 8.0.3 | yes |
| OpenCV (with `dnn`) | `opencv`, `python3-opencv` 4.12.0 | 8.0.3 | yes |
| ncnn | `ncnn`, `python3-ncnn` | 8.0.5 | yes |
| ONNX (format only, no `onnxruntime` found) | `onnx`, `python3-onnx` 1.20.1 | 8.0.5 | yes |
| llama.cpp | `llama.cpp`, `llama-server` | 8.0.3 | no (HTTP server) |
| whisper.cpp | `whisper.cpp` | 8.0.5 | no |
| mlpack, XNNPACK | | 8.0.3 | no |
| PyTorch 2.3.1, TensorFlow 2.16.1 | cross-build only | 8.0.0 / 7.1 | - |

Also there: `python3-numpy`, `python3-scipy`, and `ros2-jazzy` (+ `-control`, `-nav2`,
`-moveit2`) as `apk`. The source port of ROS 2 (`qnx-ports/build-files`, `ports/ros2`) is
Humble, needs a Linux host with Docker and recommends 32 GB of RAM.

Fallback AI module if the contact model has no data in time: MediaPipe. The mirror teleop
already uses it (`application/backend/app/mirror/tracker.py`), so the hand tracker could move
to the Pi with no new model.

## Risks, highest first

1. **The USB servo adapter on QNX** (way 2 only). QNX uses `devc-serusb`, the port is
   `/dev/serusb1`, and the docs list no chips. First thing on a booted Pi:
   `devc-serusb -d query_modules`. If the adapter's chip is not there, way 2 is dead.
2. **Data.** Free sweeps and blocked sweeps on the real hand. Only the thumb is calibrated, so
   a thumb-only model is the realistic first result.
3. **Labels.** Simplest: an object at a known position, label = contact once the finger is at
   it. Bad labels give a model worse than the threshold.
4. **ROS 2 on the Pi** (way 2 only). The prebuilt one is Jazzy, the workspace is Humble: DDS
   across distros is not supported, often works for `std_msgs`, not tested. The Humble source
   build takes hours. A way around both: no ROS on the Pi, the HAL as plain Python behind a
   small UDP bridge, the ROS node on the laptop as the relay.
5. **Honest value.** The threshold already works. Show a plot of both detectors on the same
   recording (the model earlier, and quiet on a free start), or it reads as a threshold with
   extra steps.
6. `pyserial` on QNX: pure Python on termios, should work, not tested.

## Not verified

- The `apk` repository URL for the Pi image (the QNX Quick Start docs should say).
- What `hosted` in the dashboard API means (false for `python3-tflite-runtime`).
- That the `apk` packages of 8.0.3 install on the Quick Start image's QNX version.

## Open questions

- Way 1 only, or way 2 as well? (Depends on the `devc-serusb` test.)
- Contact / no contact, or also the kind of contact (soft object, hard stop, jam)? Proposal:
  contact only; the kinds need about three times the data.
- Which Pi is there? Pi 4 is the tested target of the ROS 2 port; the dashboard has Pi 5 too.

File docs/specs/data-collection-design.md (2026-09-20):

# Data collection: demonstrations from backdriven fingers

How the demonstrations for SmolVLA are recorded and
labelled. Status: implemented; record and
label run end to end without hardware, not yet against the hand. Date: 2026-09-19. This closes
"the data collection method" of `policy-link-design.md` (Scope, Out).

> **2026-09-19, result on the real hand: backdrive does not work with these
> servos.** The fingers are too stiff to move by hand, see "Backdrive result"
> below. The method of this document (torque off, labels from the encoders) is
> not usable on this hardware. The recorder, the label script and the HAL
> passive mode work as described and stay; the source of the actions must
> change to commands with the torque on (`require_passive=false`, a teleoperator
> that reads `/hand/command`). That design is not written yet.

## Decisions

- Backdrive is a mode for data collection only. During a demonstration the
  torque is off, a person moves the fingers, and the encoders give the motion.
  In operation the servos have torque and the policy moves the fingers. There is no
  second input device and no new topic: the recorder needs only `/hand/state`
  and the camera.
- The label comes from the encoders: the action at frame `t` is the state at
  frame `t + k`, stretched by a grip gain (see `label.py`).
- `lerobot-record` writes the dataset (LeRobotDataset: video, state, action).
  There is no storage format of ours. SmolVLA trains on it directly.
- The recording holds the raw encoder values as the action. The shift and the
  grip gain are applied offline, so `k` and the gain can change with no new
  recording.
- The hand gets no commands during a recording.
- The datasets are stored in `policy/datasets/` on the GPU laptop, a folder
  that git ignores. Nothing is stored on the wearable machine.

## Scope

In: a LeRobot `Teleoperator` that returns `/hand/state`, a `passive` switch on
`ExoHand`, the offline label script, their tests, the README commands, the
`.gitignore` entry for `policy/datasets/`.

Out:
- The HAL passive mode (torque off, `/hand/state` still published). **Built**
  (2026-09-19): service `/hand/set_passive`, latched `/hand/passive`, launch arg
  `passive:=true`, toggles in the control window and the web console; see
  `physical_layer/CLAUDE.md`. Leaving the mode holds the measured pose and
  publishes it once on `/hand/command`, so the "hand jumps when the torque comes
  back" row below no longer applies to the HAL itself. The recorder depends
  only on `/hand/state`.
- Depth (RGB only, as in `policy-link-design.md`).
- Force control. The HAL does position control; the only force value is
  `servos.torque_limit` in `hand_params.yaml`.
- Training, dataset hosting (open question in `../system-design.md`), the
  release signal.

## Data flow

```
wearable ROS machine                              GPU laptop
  HAL (torque off) --/hand/state-----+                   +--> ExoHand (passive)  --observation--+
  camera --/camera/color/.../compressed--> rosbridge ==ws:9090==                                +--> lerobot-record --> dataset
                                                         +--> ExoHandLeader     --action-------+          |
                                                                                              label script (offline)
                                                                                                          |
                                                                                                   training dataset
```

## Components

### `ExoHandLeader` - the teleoperator

In the package `lerobot_robot_exo_hand` (no second distribution):
`config_exo_hand_leader.py` has `ExoHandLeaderConfig`, registered as
`exo_hand_leader`; `exo_hand_leader.py` has `ExoHandLeader`. `__init__.py`
imports the two. lerobot imports the package because of its
`lerobot_robot_` name, and it finds the class from the config name without
`Config` in `config_x` -> `x` (`make_device_from_device_class`).

- Config: `host`, `port = 9090`, `max_age_s = 0.3`, `connect_timeout_s = 10`.
- `connect()`: own `roslibpy.Ros`, subscribes to `/hand/state` with
  `queue_length=1`, waits for the first message. The record loop of lerobot
  0.6.1 gives the observation to the teleoperator only for one robot type
  (`unitree_g1`), so the teleoperator cannot take the state from `ExoHand` and
  needs its own connection.
- `get_action()`: the latest state as `thumb.pos` .. `pinky.pos`, the keys of
  `ExoHand.action_features`. Raises `ConnectionError` if the state is older
  than `max_age_s`, as `ExoHand.get_observation()` does.
- `require_passive = True`: `connect()` and each `get_action()` raise unless the
  latched `/hand/passive` of the HAL is true. With torque the fingers do not
  move, and the recorder would store constant labels with no error. An
  unknown mode counts as not passive. Set it to false for a recording where
  something else commands the hand.
- `action_features`: the 5 keys, float. `feedback_features`: empty.
  `send_feedback`, `calibrate`, `configure`: nothing.
- It reuses `KEYS`, `is_fresh` and `to_observation`-style helpers of
  `convert.py`. No lerobot import in the pure parts.

### `passive` on `ExoHandConfig`

`passive: bool = False`. If it is true, `send_action()` publishes nothing and
returns the action. `lerobot-record` calls `send_action()` with each
teleoperator action; without the switch the adapter publishes the encoder
positions as commands, and the hand jumps to the last one when the torque
comes back. The dataset is not affected: lerobot stores the teleoperator
action, not the return value of `send_action()`.

Without `passive`, `send_action()` raises if the HAL reports passive mode: a
passive HAL ignores `/hand/command`, so a policy would run and the hand would
not move.

### `label.py` - the offline label script

Pure function, no lerobot import:

```
label(states: N x 5, k, gain) -> N x 5
  out[t] = min(1, states[min(t + k, N - 1)] * (1 + gain))
```

- `k` (frames, default 3 = 0.2 s at 15 fps): without the shift, the action is
  equal to the state in the same frame, and the policy learns to copy its
  input. The hand then does not move. The last `k` frames of an episode use
  the last state.
- `gain` (default 0.2): backdriven fingers stop at the surface of the object,
  so the raw label is the contact position. A position servo at its target
  applies almost no force, and the object slips. The gain puts the target past
  the contact, and `torque_limit` then sets the grip force. A proportional
  gain keeps open at `0`; a constant offset does not let the hand open fully.
- The command-line part reads a recorded dataset, applies `label` for each
  episode to the `action` column (from `observation.state`, not from the old
  action, so it can run again with other values), and writes a new dataset
  (`<root>_k3_g20`). The raw dataset stays as it is. The whole folder is
  copied (the videos are not encoded again), the `action` column of the
  parquet files is written again, and `recompute_stats` of lerobot makes a new
  `meta/stats.json`, which the training uses for normalization.
- Both values are tuning knobs. `k` and `gain` go in the name of the output
  dataset, so a checkpoint is traceable to its labels.

### README

```bash
lerobot-record \
    --robot.type=exo_hand --robot.host=<ros-ip> --robot.id=exo --robot.passive=true \
    --teleop.type=exo_hand_leader --teleop.host=<ros-ip> --teleop.id=exo \
    --dataset.repo_id=<user>/exo_grasp_raw --dataset.push_to_hub=false \
    --dataset.root=policy/datasets/exo_grasp_raw \
    --dataset.single_task="grasp and put down objects, make a peace sign at a person" \
    --dataset.fps=15 --dataset.num_episodes=50 \
    --dataset.episode_time_s=20 --dataset.reset_time_s=5

python -m lerobot_robot_exo_hand.label --root=policy/datasets/exo_grasp_raw --k=3 --gain=0.2
```

The commands run from the repo root. In lerobot 0.6.1 `root` is the folder of
the dataset itself, not a parent folder, so each dataset has its own `root`.
The label script writes `policy/datasets/exo_grasp_raw_k3_g20`.

### Storage

`policy/datasets/` is in `.gitignore`: the video shows people, and the files
are large for git. The folder is not a cache. The demonstrations cannot be
made again without a new recording session, and `git clean -fdx` deletes
ignored folders: make a copy outside the repo after each session. The default
of lerobot (`~/.cache/huggingface/lerobot/`) is not used, because a cache
clean-up can delete it.

A dataset layout: `data/` (parquet: state, action, timestamps), `videos/`
(MP4), `meta/` (features, episode index, statistics). ~100 episodes at
640x480 and 15 fps are some hundreds of MB.

The transfer to the training machine is open: `rsync` of the folder, or a
private Hugging Face dataset repository.

`push_to_hub=false` until the dataset storage question is closed: the video
shows people.

## Recording protocol

- 50 to 100 episodes for one task, 10 to 20 s each: approach, grasp, hold,
  release. Piano is a second task with its own episodes and instruction.
- Change the object position, the approach angle, the light and the
  background between episodes.
- Include episodes where the hand comes near the object and does not grasp.
  Without them the policy learns "object in view = close".
- Before the first session: backdrive one finger through its full range and
  compare `/hand/state` with the motion. Gear friction can make the motion
  unnatural.

## Failure behaviour

| Event | Result |
|---|---|
| WiFi drops or the camera stops | `get_observation()` or `get_action()` raises after `max_age_s`; `lerobot-record` stops. Record the episode again. |
| Torque is on during a recording | The leader raises at `connect()`, or at the next `get_action()` if the mode changes in a session (`require_passive`). |
| `passive` is not set | The adapter publishes encoder positions to `/hand/command`. No effect while the torque is off; the hand jumps when the torque comes back. |

## Tests

Plain `pytest`, no rosbridge:

- `label`: shift by `k`; the last `k` rows hold the last state; `0` stays `0`;
  the result is never more than `1`; `k = 0, gain = 0` is the identity.
- `ExoHandLeader.get_action()`: the keys are equal to
  `ExoHand.action_features`; it raises with no state and with an old state
  (callbacks fed directly, as in `test_exo_hand.py`).
- `ExoHand` with `passive`: `send_action()` publishes nothing.

Success criterion for the full path: a 2-episode recording against the real
hand, then `label`, then a load of the output with `LeRobotDataset` that shows
`action[t] == min(1, state[t+3] * 1.2)`.

## Risks

1. Grip force is indirect (gain + `torque_limit`). One value for all objects
   is possibly not sufficient; bottle and piano possibly need different
   limits.
2. Distribution shift: a person moves the fingers in the recording, the servos
   move them in inference. The speed profile is different. The shift and the
   action chunks decrease the effect but do not remove it.
3. The friction of backdriven gears (see Recording protocol).

## Backdrive result

Tested on 2026-09-19 on the thumb of the real hand (Feetech ST servos, ids 1 to
5 on the bus, low torque limits).

- Torque off (HAL passive mode): the HAL side works, all 5 servos answer and
  `/hand/state` is published. The finger is too stiff to move by hand. The
  cause is the friction of the high-ratio gear train, multiplied by the three
  four-bar linkages of the finger. The motor is not the cause.
- Active backdrive, tried as a throwaway `servo_tool follow` (not in the repo).
  Four versions, all in position mode and with the encoder as the only sensor:
  1. The goal follows the finger when the offset is above a deadband. Harder to
     push than with the torque off: the servo holds the goal against the push.
  2. The goal leads the finger after a push (`lead`). Vibrates: the encoder
     noise (1 to 2 steps) is as large as the signal.
  3. Admittance, the offset is integrated to a goal speed. Limit cycle with
     hands off: the standing offset from the gear play looks like a push. With
     a deadband that stops it, the finger is again too hard to move.
  4. Goal = position + assist x measured speed (motor power proportional to the
     speed of the push, no goal at rest). The best one: no vibration, lighter
     during the motion. The start still needs a hard push, because the motor
     sees nothing before the static friction breaks. Dither was added and not
     evaluated.
- A hard push against a holding motor gave 6.5 to 13 mA on register 69 (present
  current): the gear friction carries the load, so neither the current nor the
  encoder shows a push before the gears move.
- Not tried: the PWM mode of the servo (operating mode register, EEPROM). A
  light feel needs a force sensor at the finger, an elastic link, or servos
  with a lower gear ratio.

## Not verified

- The recording against the real hand in passive mode. On 2026-09-19 the
  record and label commands ran end to end against the HAL node with the sim
  backend, rosbridge and a fake camera (2 episodes, 150 frames, AV1 video):
  `action[t] == min(1, state[t+3] * 1.2)` holds in each episode. The run found
  that `lerobot-record` reads `robot.cameras`; `ExoHand` has it since then.
- The raw action and the state of one frame differ by up to one sample (0.04
  in the test), because the robot and the leader have separate connections.
  The labels come from `observation.state`, so this has no effect on them.

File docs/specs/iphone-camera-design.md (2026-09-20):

# iPhone head camera: from the backend into ROS

How the forehead iPhone becomes a ROS camera, so that the recorder and the policy
read it the same way as the RealSense. Status: built on 2026-09-19 (the node, `ExoHand`,
the backend and the frontend), tested on a fake phone and run with no phone; NOT yet run
with a real phone - the done checks of the work order are open. Date: 2026-09-19. It closes the TODO "the forehead iPhone as a ROS topic" of
`mirror-teleop-design.md`.

Scope: a ROS node that owns the phone, the contract topics, the second image key
in `ExoHand`, and the removal of the Record3D client from the web backend. Not in
scope: iPhone depth, the recording console, training.

## Decisions

- **A ROS node owns the phone**, not the web backend. The policy cameras then do
  not depend on a running web console, and the backend is again a pure consumer
  of ROS.
- **USB only.** The phone is on the wearer, and the wearable machine is too. The
  Wi-Fi / WebRTC transport of Record3D is deleted, not moved.
- **Colour only for the policy.** The policy does not use iPhone depth, and the console has no
  iPhone depth view. The depth became necessary the same day, for the console's object map on a
  bench with only the phone: the node publishes it as 16UC1 millimetres `compressedDepth` on
  `/head_camera/aligned_depth_to_color/image_raw/compressedDepth`, turned and sized as the colour
  picture (node parameter `depth`, default true). The backend's detector takes the head camera
  while the wrist camera is silent; the objects are then where the HEAD sees them, drawn around
  the hand all the same (nothing knows where the head is).
- **Only `/compressed` and `camera_info`.** All consumers are on rosbridge, where
  a raw image is base64 JSON. No `image_raw`.
- **The node fixes the rotation and the size.** They are part of the dataset: a
  change after the first recording makes the old episodes wrong. They are node
  parameters, not a console button.
- **Image key `camera1`.** `smolvla_base` has the image slots `camera1..3`, and
  async inference has no `rename_map` (`policy-link-design.md`, The camera key).
  The wrist RealSense stays `camera2`. Datasets recorded with one camera do not
  mix with datasets of two.

## Contract (add to the root `CLAUDE.md`)

The head camera is `/head_camera/color/image_raw/compressed`
(`sensor_msgs/CompressedImage`, `jpeg`, 640 x 480, landscape, max 15 fps) with
`/head_camera/color/camera_info` next to it. `header.stamp` is the ROS time at
which the frame arrived; `frame_id` is `head_camera_color_optical_frame` (no TF:
the head is not attached to the hand). Nothing outside the camera launch file
knows it is an iPhone.

## Flow

```
iPhone (Record3D app, USB Streaming mode)
   | USB, usbmuxd
wearable ROS machine
   child process: record3d library  --pipe: rgb-->  iphone_camera_node
                                                       | rotate, shrink, JPEG
                                          /head_camera/color/image_raw/compressed
                                          /head_camera/color/camera_info
                                                       |
                                                   rosbridge :9090
                                     +-----------------+------------------+
                              web backend                         ExoHand (GPU laptop)
                        WS /ws/camera/iphone/color          observation.images.camera1
```

## The node

`htn_control/iphone_camera_node.py` + `htn_control/iphone_worker.py`, entry point
`iphone_camera_node`. `camera.launch.py` starts it with
`head_camera:=iphone` (default `none`: a launch with no phone must not print
errors without end).

- **The worker** is `application/backend/app/usb_worker.py`, moved: the library
  runs in a child process, and a stop kills that process. The reason does not
  change: the library's `disconnect()` never closes its socket, and the phone then
  refuses the next client. The worker sends only `rgb` (no depth copy), drops
  frames above the rate cap before the copy, and exits when its parent dies.
- **The node** reads the pipe in a thread and, for each frame: rotates, shrinks
  to `width x height`, encodes JPEG, stamps, publishes. Latest frame only, never
  a queue.
- **Reconnect:** when the worker ends ("no phone", "not serving", stream
  stopped), the node starts a new worker after a backoff of 1 .. 8 s. It logs the
  reason once per change of reason, not once per try. The texts that say what to
  do on the phone (`NO_PHONE`, `NOT_ACCEPTING`, `USB_STUCK`) move with the worker.
- **`camera_info`:** K from the intrinsics that the library gives
  (`get_intrinsic_mat()`), transformed for the rotation and scaled for the shrink.
  No distortion (`D` = zeros). Published with each frame, same stamp.

Parameters:

| Parameter | Default | |
|---|---|---|
| `rotation` | `270` | clockwise degrees, `0 / 90 / 180 / 270`. The sensor is portrait; 270 = landscape with the phone's charge port to the left, which is how it sits on the forehead mount (90 came out upside down). |
| `width`, `height` | `640`, `480` | the output size. The phone's 4:3 picture fits with no crop. |
| `max_fps` | `15` | the phone sends 60. 15 = the RealSense colour profile and the rate of the policy link. |
| `jpeg_quality` | `80` | |

## Set-up of the wearable machine (verify FIRST)

This is the risk of the design. Do it before any other work; if it fails, stop
and go back to the fallback below.

1. In the ROS environment (container or native):
   `python3 -m pip install --user --no-deps record3d==1.4.1` (`--no-deps`: it must not
   pull numpy 2 over the numpy that ROS and `cv2` use). Confirmed on x86-64, Python 3.10
   (Humble), native: it is a wheel, nothing compiles, and it imports next to numpy 1.26.
   Not confirmed on ARM (Pi 5): there it may build native code (`cmake`, a C++ compiler).
2. The library talks to the host's `usbmuxd` through `/var/run/usbmuxd`. In a
   distrobox that socket must be visible in the container. Not confirmed.
3. Check: a 10-line script in that environment prints the shape of one frame.

Fallback if 1 .. 3 fail: the backend keeps the phone and publishes the same
topic through rosbridge (`roslibpy`), and must then run where the phone is. The
contract, `ExoHand` and the console stay as in this spec.

## `ExoHand` (`policy/`)

- Config: `head_topic: str = "/head_camera/color/image_raw/compressed"`,
  `head_width = 640`, `head_height = 480`. An empty `head_topic` = one camera,
  the behaviour of today (for the old datasets and for a bench with no phone).
- `convert.py`: `HEAD_CAMERA = "camera1"`; `to_observation` takes the head image
  as an optional argument.
- A second subscription with its own arrival stamp. `is_fresh` already takes a
  collection of stamps: the head stamp goes into it, so a dead phone stops the
  client the same way as a dead RealSense ("the hand holds").
- The two images of one observation are the latest of each, not synchronized.
  At 15 fps the skew is at most ~70 ms. Accepted.

## Web backend and frontend

Delete:

- `app/record3d.py`, `app/usb_worker.py`, `tests/test_record3d.py`,
  `tests/fake_record3d.py`; `record3d` and `aiortc` from `requirements.txt`
  (keep `av` only if something else imports it after the change).
- `GET / POST /api/iphone`, `PhoneSettings`, `RECORD3D_HOST`,
  `RECORD3D_ROTATION`, `hub.iphone_rotation`, `run_iphone_worker`,
  `on_iphone_frame`.
- Frontend: `phone-connect.tsx`, `use-phone.ts`, the rotate button, the RGB /
  DEPTH toggle of the iPhone panel, the phone types.

Change:

- `ros_client.py` subscribes `/head_camera/color/image_raw/compressed` with the
  same throttle as the RealSense colour; `hub.on_head_color` passes the JPEG
  bytes through untouched to `frames["iphone"]["color"]`.
- `WS /ws/camera/iphone/depth` is removed; `WS /ws/camera/iphone/color` stays
  (the source keeps the name `iphone` in the API: a rename gives nothing).
- The iPhone panel with no frames shows "no frames: start `head_camera:=iphone`,
  see the node log". The phone instructions are in the node log only.
- Mock mode: the mock phone publishes its colour image directly; the Record3D
  side-by-side packing in `mock.py` goes.
- `application/CONTRACT.md`: the section "iPhone side (Record3D, not ROS)" goes;
  the API list and the file list follow the changes above.

## Tests (TDD, no phone, no ROS where possible)

Pure functions in `htn_control`, tested with `pytest` as the other HAL parts:

- `prepare(rgb, rotation, width, height)`: a portrait frame with one marked
  corner comes out `480 x 640 x 3` with that corner where the rotation puts it,
  for all four rotations.
- `camera_matrix(K, shape, rotation, width, height)`: the principal point of a
  frame follows the same marked corner; `fx / fy` swap at 90 and 270.
- The rate cap: a fake clock, 60 fps in, no two accepted frames closer than
  `0.9 / max_fps`.
- The worker with a fake stream (the `make_stream` argument that `usb_worker.run`
  has today): "no device" and "connect refused" give the error messages; a frame
  gives `("frame", rgb)`.
- The node's reconnect: a worker that ends is started again after the backoff,
  and the reason is logged once.

`policy/`:

- `to_observation` with a head image has `camera1` and `camera2`; without, only
  `camera2`.
- `ExoHand` with a fresh state and a fresh wrist frame but an old head frame
  raises `ConnectionError`; with `head_topic = ""` it does not.
- `observation_features` has the two image keys with their shapes.

Backend: `test_hub` - a head JPEG goes to the `iphone / color` channel
untouched; `test_mock_api` follows the removed endpoints.

## Work order

1. The set-up check above, on the machine that will be worn.
2. The node: pure parts with tests, the worker (moved), the node, the launch
   argument, `physical_layer/CLAUDE.md`. Done check: `ros2 topic hz` shows
   ~15 Hz, Foxglove shows the image the right way up.
3. `ExoHand`: second key, with tests. Done check: the `__main__` smoke print
   shows the two shapes.
4. Backend and frontend: the subscription, then the deletions. Done check: the
   iPhone panel shows the image with no `/api/iphone` call.
5. The root `CLAUDE.md` contract, `application/CONTRACT.md`,
   `policy-link-design.md` (one camera -> two), `next-work.md`.

## Not verified

- Steps 1 .. 3 of the set-up (the `record3d` build, the usbmuxd socket in the
  container, ARM).
- rosbridge CPU load with two JPEG streams and two clients each, on a Pi
  (already open in `policy-link-design.md` for one stream).
- The rotation value for the forehead mount.
- That `get_intrinsic_mat()` is valid before the first frame: not needed any more, the
  worker reads it in each frame callback and sends it with the frame.
- The node with a real phone: the picture size it sends over USB, ~15 Hz on
  `camera_info`, the image the right way up in Foxglove.

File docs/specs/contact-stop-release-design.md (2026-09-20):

# Contact stop: a block that stays, and a sign of it in the console

Status: design, agreed in the discussion of 2026-09-20. Built the same day, on the fake servo
bus only: nothing of it has run on the real hand ("On the hand" below). It changes the
"Blocked" and "Released" rules of `hal-safety-design.md` and adds one topic.

## The problem

On the hand the contact stop seems to do nothing: a person can resist a finger through a whole
move and it never goes soft.

It does trigger. It lets go again one cycle later. A probe log of the index finger (a close at
probe speed 2.0, `torque_limit` 600, a person resisting the whole move; commit `6447865`,
`free.csv`), replayed through `hal/contact.py`:

```
0.19 s  110 mA  excess  10
0.22 s  130 mA  excess  40
0.24 s  169 mA  excess 109
0.26 s  221 mA  -> blocked
0.28 s  247 mA  -> free
0.30 s  286 mA  -> blocked
0.32 s  254 mA  -> free        ... and so on to the end of the move
```

The cause is the release rule "the finger moves again": more than `hold_lead / 2` (0.015 of the
travel) past the point where it got blocked. A finger at speed covers 0.04 of the travel in one
cycle, so its own momentum frees it in the next cycle. The servo gets `hold_torque` for 20 ms
and the full `torque_limit` again.

The replay uses positions recorded at the full torque. On the hand one cycle of low torque slows
the finger a little; 20 ms is not expected to stop it. Not measured.

A second fault in the same place: the hold setpoint is frozen at the blocked position +
`hold_lead` (0.03). A finger that coasts past it has the setpoint BEHIND it, and the servo pulls
it back, off the object.

## What the logs say about the current

From the same two logs (`free.csv`, `trial.csv`), all moves at the same constant speed of 32 to
33 steps per cycle:

| Move | Load (drive level, 0..1000) | Current at constant speed |
|---|---|---|
| index close, resisted by hand | 590 | 234 to 292 mA |
| index open, free | 465 | 52 to 72 mA |
| other finger close, free | 468 | 46 to 65 mA |

- The current tells a free move from a resisted one by a factor of about 4. Free motion stays
  below 91 mA, start peaks included. `blocked_current` 100 is right above that: the threshold is
  not the problem.
- The finger kept the full commanded speed while resisted: the servo raised its drive level and
  pushed through. So "slower than commanded" does not show a soft resistance; the current does.
- `hal-safety-design.md` says the index draws up to 290 mA on a FREE close and trips on every
  close. That number is from a resisted move. The index needs no threshold of its own.
- The finger needs about 0.32 s to reach its speed (the HAL's ramp is 0.07 s), and the current
  hardly drops after it. A higher threshold while the setpoint accelerates gains little.

Valid near probe speed 2.0 and `torque_limit` 600 only. The HAL runs at `max_speed` 4.0 and
`torque_limit` is 700 now: the free current there is not known.

## Design

### Detector (`hal/contact.py`)

| | Now | New |
|---|---|---|
| Blocked | the summed excess current, OR the encoder rule (far from the setpoint and not moving for 0.2 s) | the summed excess current only |
| Hold setpoint while blocked | blocked position + `hold_lead`, frozen | furthest position reached in the blocked direction + `hold_lead`: it follows the finger forward and never goes back |
| Release by motion | more than `hold_lead / 2` past the blocked position | more than `release_travel` past the blocked position |
| Release by command | the target is on the other side of the finger | the same |

- The servo always pushes toward the object with `hold_torque`; it never pulls a finger back
  that coasted or that squeezes an object that gives way.
- `release_travel` counts from the position where the finger GOT blocked, not from the point
  that follows the finger: a finger that goes on and on is free again after that distance,
  whatever its speed.
- `release_travel: 0.15` in `contact_stop:` of `hand_params.yaml`, next to `hold_lead`. A
  tuning value: the coast after the torque drops is estimated at 0.04 to 0.08 of the travel,
  not measured.
- The encoder rule goes, out of the code, the yaml (`blocked_error`, `blocked_motion`,
  `blocked_cycles`) and the tests. It made the 39 false stops of one tune (commit `4ccee1a`),
  and a hard stall draws a high current, which the current rule sees in 1 to 4 cycles, not 10.
  `blocked_current` is no longer optional: `enabled: false` is the way to turn the stop off. A
  backend without a current reading has no contact stop (there is none with a torque limit).
- The encoder is still what RELEASES a finger (`release_travel`): on `hold_torque` the current
  is low on purpose and cannot say that the obstacle is gone.
- The summed excess current and its two thresholds do not change.

### Topic `/hand/blocked`

`std_msgs/Float64MultiArray`, 5 values in finger order, `1` = blocked, `0` = free, latched like
`/hand/passive`. The HAL publishes it at the start (all 0) and whenever a finger changes state.
A float array, not a byte array: rosbridge hands it over as a plain JSON list, like the other
hand topics. A new entry in "Contracts that cross folders" of the root `CLAUDE.md`.

The sim never publishes a 1: `SimBackend` has no torque limit, so the HAL makes no detectors.

### Topic `/hand/current`

Added the same day, to tune on the hand: the motor currents the detector decides on, 5 values in
mA, every cycle, from a backend that measures them (not the sim). The console shows per finger the
peak of the last 0.5 s next to its slider.

### Web console

- Backend: `blocked` (5 booleans) in the `/ws/state` JSON next to `passive`, from the topic. All
  false until the first message, and in the mock. `application/CONTRACT.md` gets the field.
- 3D view: the contact pad of a blocked finger, on the MEASURED hand, takes the accent colour
  (`SIGNAL` in `hand-model.ts`). Nothing else changes: a blocked finger is a normal state of a
  grasp, not a fault, and the sign must be subtle.
- Telemetry block: the finger's row in the command block takes the accent colour.
- Live state only, no history. A block shorter than one state message is not seen.

## Not in this work

- `max_speed` stays a launch argument. The logs say the servo is near its limit at about 2.0
  travels/s: a higher `max_speed` does not make the real finger faster and raises the free
  current, against the contact stop. Decide after the tests on the hand.
- No expected-speed model, no threshold per finger or per direction, no threshold that depends
  on the acceleration. The logs give no reason for them.
- No switch for a movement to turn the stop off.

## Tests

- `test_contact.py`: rows of the resisted log, inline. The finger gets blocked and STAYS blocked
  over the next `release_travel` of travel (before: free one cycle later). The log was recorded
  at the full torque, so the finger in it goes on to the end; on the hand the low torque stops
  it. While blocked, the hold setpoint is never behind the finger. A blocked finger that then travels more than `release_travel` is free. A finger far
  from its setpoint that does not move, at a low current, stays free. The tests of the encoder
  rule go; release by command keeps passing.
- HAL on the fake servo bus: `/hand/blocked` says 1 for a finger driven against a stop, 0 after
  the open command.
- Backend: a `/hand/blocked` message shows up as `blocked` in the state JSON.
- Frontend: no test, the change is a colour.

## On the hand, after the build

1. Resist a finger by hand: ONE `blocked` line in the HAL log and the pad lights, until the
   finger is let go and has moved on, or the command opens it. Many blocked / free pairs = the
   coast is longer than `release_travel`.
2. Free moves of every finger at `max_speed` 4.0: no block. A block here = the free current at
   this speed is above `blocked_current`; read the mA in the log line, then raise it or lower
   `max_speed`.
3. Hot cross buns on the keys, and a grasp of the bottle. Tune `hold_torque`, `blocked_current`
   and `release_travel` from what the log shows.

## Risks

- With the encoder rule gone, a current reading that fails or sticks at 0 leaves a jammed finger
  on the full `torque_limit`. Not likely: the current comes in the same 15-byte block as the
  position. The servo's own overload protection is the layer below.
- A false stop makes the finger crawl on `hold_torque` for 0.15 of the travel before it is free
  again. At 4.0 / 700 false stops are likely until step 2 is done.
- An object that gives way more than `release_travel` (a sponge) gets pulses: full torque,
  blocked, full torque.
- `hold_torque` 60 may be too little to press a piano key down once the stop really holds. Until
  now the tune ran with a stop that did not hold.
- If the coast is longer than 0.15, the flapping is back, slower. The pad then flickers.

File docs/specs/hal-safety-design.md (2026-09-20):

# HAL safety: calibration and the contact stop

The next work on the real hand. Status: design notes from the discussion and
the hardware tests of 2026-09-19. **Implemented later that day, on the fake
servo bus only** - see "What is built" at the end; nothing of it has run on the
real hand, and the thresholds are untuned.

## State of the real hand (2026-09-19)

- 5 Feetech ST servos on the Waveshare adapter (CH343, `/dev/ttyACM0`, 1 Mbaud).
  They had all the factory id 1 (scan showed a checksum error on id 1: identical
  ping replies overlap cleanly, position replies collide). Numbered with
  `servo_tool set-id`, one servo on the bus at a time: thumb 1 .. pinky 5. The
  HAL finds all 5.
- **The calibration is still the placeholder**: `open_step: 2048`,
  `closed_step: 3072` for every finger in `hand_params.yaml`.
- The development laptop runs ROS **Kilted** in the distrobox `ros` (no Gazebo,
  no `ros2_control`, no RealSense driver): use `hardware.launch.py camera:=none`.
  After a pull that adds files, run `physical_layer/build.sh`.

## Hazards found

1. **Placeholder calibration + active launch**: the HAL starts with the
   setpoint "open" (step 2048), not with the measured pose, and drives there
   with the full torque limit. `max_speed` does not help.
2. **Exit of passive mode**: the HAL clamps the measured pose to `0..1` and
   makes it the goal before the torque comes on. A finger outside the
   (placeholder) range jumps to the range edge.
3. **Torque pulse at start with `passive:=true`**: `FeetechBackend.__init__`
   enables the torque for every servo before the HAL sets it off. A servo that
   kept power can hold an old goal for some milliseconds. Fix: do not enable the
   torque when the start is passive.
4. `servo_tool scan` stops at the first servo with a bad read, so it does not
   diagnose "several servos on one id". Fix: catch the error, print it, go on.

## What the torque limit does (measured)

Register 48 caps the drive duty cycle. It lowers the speed AND the stall
torque together: at 100 of 1000 the finger is slow and still does not stall on
a hand. It is the safety ceiling, not a grip-force control. Force and speed
need separate knobs.

## Contact stop (the motor stop that protects the parts)

Purpose: a finger that meets resistance, in ANY direction, must stop pushing
hard. This protects the linkage (wrong calibration, a jam, the open stop) and
it sets the grip force on an object.

| State of a finger | Torque limit (register 48, RAM, written by the HAL) | Setpoint |
|---|---|---|
| free | `torque_limit` (high: speed, and the ceiling) | ramps to the target at `max_speed` |
| blocked | `hold_torque` (low: the force we want) | just past the furthest position the finger reached, in the blocked direction |

**Changed on 2026-09-20** (`contact-stop-release-design.md`): blocked = the current rule ONLY,
the encoder rule below is gone; released by motion = `release_travel` (0.15) past the block, not
"it moves again" - a finger at speed met that with its own momentum one cycle after the block, so
on the hand the stop never held. The notes below are the history.

- **Blocked** = the finger must move and does not: the setpoint is more than
  `blocked_error` from the measured position, and the measured position changed
  by less than `blocked_motion` over the last `blocked_cycles` cycles. Not the
  lag alone: a slow servo (low torque limit) lags in free motion too.
- The window of "does not move" holds only cycles in which the finger has to move (it is
  emptied whenever the error is small), and movement is max - min over it. Found on the hand
  at `max_speed` 4.0 (2026-09-19): with the rest before a command in the window every quick
  start was blocked at once (39 blocks in one tune, all at 0 - 32 mA), and a finger turning
  around far from its setpoint ended the window where it began. Each false block put the
  finger on `hold_torque` and made it crawl: a key stroke took about a second.
- **Released** when the command goes to the other side of the finger, or when
  the encoder shows that the finger moves again (the obstacle is gone). The
  full torque returns. The current cannot be the release signal: it is low in
  the hold state on purpose.
- Each finger alone. `/hand/state` stays the measured position.
- Force before the detection is still `torque_limit` for ~0.1 to 0.2 s.
- Current (register 69, unit 6.5 mA) is the first contact signal since 2026-09-19: blocked
  when the mA above `blocked_current` (100 mA, found on the hand with `servo_tool probe`),
  summed over the cycles, reach `blocked_excess` (150); a cycle below the threshold takes
  its shortfall off the sum. One huge cycle blocks at once, a small overload after some
  cycles, and the peak of a free start (34 on the middle finger) drains away. It replaced
  "5 cycles in a row", which let a hard contact push at the full torque limit for 0.1 s. The encoder rule missed a
  finger stopped closer than `blocked_error` to its target and one that creeps into
  something soft; it stays as the fallback, and it is the only rule on a backend without
  a current reading. Free motion at torque limit 600 draws 60 to 110 mA in short peaks
  (the start of a move), so the margin is small. The index drew up to 290 mA on a close at
  max_speed 2.0 - a person was resisting that move; its free open stayed below 91 mA, so it needs no
  threshold of its own. An earlier measurement (a push by hand against a HOLDING motor: only
  6.5 to 13 mA, the gear friction carries the load) still stands - the current shows what
  the motor drives into, not what pushes on a finger at rest.
- Not chosen: the overload protection inside the servo (EEPROM: overload
  torque, protection time, protective torque; protection current). It is a
  trip, the finger goes limp, recovery is unclear, and the values would live in
  the servo and not in `hand_params.yaml`. Possible later as a last backstop.
- Not chosen: force from the distance of the frozen setpoint (`squeeze`). The
  servo gave ~1.3 % drive for each step of error (load 52 at error 4), and
  where that saturates is unknown, so distance is not a reliable force knob.

Files: a pure module `hal/contact.py` (the state logic, no ROS) with tests;
`set_torque_limit(finger, value)` on the backend (nothing in the sim); a few
lines in `hal_node.update()`; `hold_torque` and the `blocked_*` values in
`hand_params.yaml`; a HAL test on the fake servo bus, extended so that a fake
servo can have a mechanical stop. The thresholds need tuning on the hand.

## Calibration

- One-time tool `servo_tool calibrate`, NOT a routine at each start: the
  encoders are absolute, so the values survive a power cycle (they are lost
  only if a horn is mounted again), and a start routine would move a hand that
  a person wears, where "resistance" can be a finger joint.
- Motor-driven, with the SAME blocked detector as the contact stop (one logic,
  two callers): low torque, one finger at a time, drive slowly toward open
  until blocked -> `open_step`.
- **Open side only.** The linkage binds at 84 to 100 deg horn angle, past the
  closed position; driving "until resistance" there can lock it.
  `closed_step = open_step +- max_angle * 4096 / 360` (~830 steps), with
  `max_angle` from `hand_params.yaml`.
- The open direction is per servo (mirrored mounting): a small test motion and
  a "did it open? y/n" question, or a sign in the YAML.
- The tool prints the YAML lines; the person writes them. No hand in the
  exoskeleton during the run.
- Until it exists: `servo_tool jog <id>` by hand, note the open and the closed
  step, type them into `hand_params.yaml` (no rebuild, restart the launch).

## What is built (2026-09-19, fake servo bus only)

- Hazards 1-4 are fixed. The backend no longer enables the torque in its
  constructor. The HAL adopts the first measured pose (NOT clamped), gives the
  motors torque with that pose as the goal, and sweeps a finger that is outside
  its travel into range at the normal speed; the same on the way out of passive
  mode. `servo_tool scan` reports a servo that pings but cannot be read.
- Contact stop as designed: `hal/contact.py` (pure), `set_torque_limit(finger,
  blocked)` on the backend, `servos.hold_torque` and a `contact_stop:` section in
  `hand_params.yaml`. Tests run the HAL on fake servos that move and can have a
  mechanical stop (`test_contact.py`), and `hardware.launch.py` ran end to end
  against them: blocked at the obstacle, low torque, freed by the open command.
- **The calibration is NOT motor-driven towards open, on purpose.** The linkage
  has no open stop before it binds: opening past the CAD pose it runs into its
  own toggle point after 28 deg of horn (thumb, index, pinky) or 33 deg (middle,
  ring) - `open_lock_rad` in `config/linkage.yaml`. "Drive until blocked" would
  find that point, with the pin forces a toggle brings, not the open pose.
  `servo_tool calibrate` is therefore a window where the person sets BOTH ends
  by eye (asked for: no questions, no computed closed position): pick a finger -
  only that one gets torque, and a low one - move it, "Set OPEN", move it, "Set
  CLOSED", Save into `hand_params.yaml`. A span past where the CAD says the
  linkage binds is warned about, not refused. An optional "Test" runs slowly
  between the two positions and stops pushing when the finger is blocked.
  Consequence: `closed_step` is no longer tied to `max_angle`. Normalized 1.0 is
  whatever was set as CLOSED, while the 3D views still draw 1.0 as `max_angle` of
  horn - if the set span differs much, put `span / 651.9` into `max_angle`. If a blocked-based
  open search is wanted later, it has to back off by `open_lock_rad` from the
  blocked point and needs a torque low enough for the toggle.
- The placeholder calibration spanned 1024 steps = 90 deg of horn; middle and
  ring bind at 84 deg. It now spans `max_angle` (836 / 816 steps). It is still a
  placeholder: `open_step: 2048` is a guess.

## Order

1. `hal/contact.py` + tests (the detector and the free/blocked state).
2. HAL integration + `set_torque_limit`, fake-bus test with a mechanical stop.
3. `servo_tool calibrate` on the same detector; fix hazards 3 and 4 on the way.
4. Tune on the hand: `hold_torque`, the `blocked_*` values, then put
   `torque_limit` back up for speed.

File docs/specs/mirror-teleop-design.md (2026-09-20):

# Mirror teleop: a second person's hand commands the exoskeleton

How the demonstrations are made now that backdrive is not usable
(`data-collection-design.md`, Backdrive result). Status: built on 2026-09-19 and
tested without hardware; the done check below has not run. It replaces the design notes of the same day
(free hand of the wearer, standalone script, OpenCV window).

Scope: data collection only. From the controller's webcam to `/hand/command`,
the panel in the web console, and the teleoperator that puts the commands into a
LeRobot recording. Not in scope: the policy cameras, the recording buttons in
the web console (next spec, "recording console"), training.

## Terms

| Term | Who | Cameras |
|---|---|---|
| **Wearer** | Has the exoskeleton on the LEFT hand, moves the arm | Wrist RealSense, forehead iPhone: the policy cameras, in the dataset |
| **Controller** | Sits at a browser; the curl of their fingers is the command | Laptop webcam: tracking only, **never in the dataset** |

## Decisions

- The controller is a second person. The wearer's own free hand is not used: a
  head camera sees it, and a policy that sees the commanding hand learns to copy
  it and fails at inference, where that hand is absent (causal confusion).
  **The controller's hand stays out of the view of both policy cameras.**
- Either hand of the controller works (no handedness in the maths). One hand in
  the webcam view.
- Record with the torque ON. `action` = the value sent on `/hand/command` (it
  goes past the contact point: `1.0` while the finger stops at `0.6`).
  `observation.state` = `/hand/state`, measured. The difference is the grip
  intent, and the contact stop of the HAL turns it into a constant soft squeeze
  (`hal-safety-design.md`). No relabel with `label.py`; look again after the
  first recording.
- Webcam frames are used for the tracking and dropped. Nothing of them goes to
  ROS or to the dataset.
- Hand tracking: **MediaPipe `HandLandmarker`** (pretrained, CPU, real time),
  **no training of ours**. `mediapipe 1.0.1` has a `py3-none-manylinux_2_28`
  wheel (checked). Not verified: whether 1.0 still has the old `solutions.hands`
  API; the design uses the Tasks API (`HandLandmarker` + a `.task` model file,
  stored in the repo, no download at run time).
- The browser is only a camera. Vision and all logic are Python, in
  `application/backend`.
- Tasks: grasps and different grip types (full grasp, pinch, tripod). The grip
  follows from the object the cameras see (one object -> one grip, always); one
  generic instruction for all episodes.
- One episode: reach with the hand open, grasp, lift, put down, release, move
  away open (~10 to 15 s). Vary object, position and approach; ~50 episodes for
  each object is the start point.
- Episodes end with the keys of `lerobot-record` (right arrow = save, left
  arrow = record again, Esc = stop) and `--dataset.episode_time_s` as the upper
  limit. Not verified: LeRobot reads the keys with `pynput`, which often does not
  work on Wayland; the fallback is the fixed episode time. Buttons in the web
  console are the next spec.

## Data flow

```
controller's browser                 backend (FastAPI, Python)                     ROS
webcam -> JPEG 320x240, 30 fps  -->  decode -> HandLandmarker (world landmarks)
          WS /ws/mirror (binary)     -> curl -> calibration -> filter -> engage -> /hand/command -> HAL
panel  <-- mode, curls, landmarks <--  (JSON on the same socket)

recorder (policy/): teleoperator `exo_hand_command` = last /hand/command  -> dataset `action`
```

One machine or several: every link is a host setting that exists
(`ROSBRIDGE_HOST`, `--robot.host`, the frontend's backend address).

## Backend: `app/mirror/`

Pure parts, each with tests and no camera:

1. **`curl.py`**: 21 world landmarks -> 5 bend angles (radians). The bend of a
   finger is the sum of the angles between successive bones, from 3D vectors:
   index = `angle(0->5, 5->6) + angle(5->6, 6->7) + angle(6->7, 7->8)`; the
   other fingers and the thumb (`0->1->2->3->4`) the same way. World landmarks
   (metres, hand-centred), not image landmarks: a finger that curls towards the
   camera moves mostly in depth. The result does not depend on the position,
   distance or rotation of the hand. The curl of one finger is ONE function, so
   the thumb can change to another measure (thumb tip to pinky base) if the
   bench check below fails.
2. **`calibration.py`**: `curl = clip((bend - open) / (fist - open), 0, 1)` for
   each finger; a capture averages ~0.5 s of bends. A calibration whose `fist -
   open` is too small for a finger is refused.
3. **`one_euro.py`**: a one-euro filter for each finger. Hand tracking jitters
   by some percent; without a filter the labels shake and the policy learns to
   shake. The HAL `max_speed` and the servo acceleration are the second and
   third stage.
4. **`engage.py`**: what is sent.

   | Mode | When | Command |
   |---|---|---|
   | `off` | Mirror switch off, or no calibration | none published |
   | `no_hand` | no landmarks in the frame (no frames at all: nothing is published) | hold the last one |
   | `following` | a hand is seen | the filtered curls |

   A hand that comes back is followed at once. The first build made the
   controller match the held pose first ("wait for a match"); on the bench five
   fingers within 0.15 in one frame was too hard to hit, and it was removed
   (2026-09-19). The cost: the command can jump after a dropout; the one-euro
   filter and the HAL `max_speed` soften it. When the calibration completes the
   held command is the current `/hand/state`, and the console captures the fist
   first and the open hand last, so the first thing the hand does is open.

Impure parts:

5. **`tracker.py`**: `HandLandmarker`, `num_hands=1`, JPEG bytes -> world
   landmarks + image landmarks (for the drawing) or `None`. Runs off the event
   loop (a worker thread); latest frame only, never a queue.
6. **`WS /ws/mirror`** in `main.py`: one client at a time (a second one is closed
   with a reason); the same `Origin` allow-list as the other sockets. It
   publishes through the existing `/hand/command` publisher of `ros_client.py`,
   **only on change** (deadband `command_tolerance`), never on a timer
   (`physical_layer/CLAUDE.md`).
7. **Mock mode** (`MOCK=1`): a synthetic hand that opens and closes, so the
   panel is built and tested with no webcam and no MediaPipe.

Config (env, defaults to tune on the bench): `MIRROR_COMMAND_TOLERANCE=0.01`, one-euro
`MIRROR_MIN_CUTOFF` / `MIRROR_BETA`. `mediapipe` goes into `requirements.txt`.

### `WS /ws/mirror` (to add to `application/CONTRACT.md`)

Client -> server: binary = one JPEG frame; JSON text =
`{"type": "calibrate", "pose": "open" | "fist"}`.

Server -> client, one JSON for each processed frame:

```json
{"mode": "following", "calibrated": true,
 "controller": [0.1, 0.8, 0.8, 0.7, 0.6],
 "command":  [0.1, 0.8, 0.8, 0.7, 0.6],
 "landmarks": [[0.41, 0.63], "... 21 image points, 0..1, or null"]}
```

As built there are two more fields, `capturing` and `error`, for the guided
calibration: `application/CONTRACT.md` is the reference. The measured state is
already in `/ws/state`.

## Frontend

- **Mirror switch** in the command block, usable only while armed, built like
  the Backdrive switch: on = open the webcam and the socket, run the guided
  calibration, lock the sliders and presets (one command source at a time).
  Disarm = off. Off or a lost connection = the hand holds the last command.
- **Guided calibration at every connect**: "fist" -> capture, "open hand" ->
  capture (a button and a shortcut for each). No `following` before it is done.
  Nothing is saved: always right for this person, camera and distance.
- **Mirror panel**: the local webcam video with the skeleton drawn from
  `landmarks`; a mode badge, red border when not `following`, with the hint
  ("put your hand in view"); it takes the place of the
  3D hand while Mirror is on; for each finger three bars:
  **ctl** (controller), **cmd** (sent), **st** (measured). Contact: cmd above st.
- Frames: a canvas at 320x240 -> JPEG -> binary message, 30 fps, skip a frame
  while the socket's buffer is not empty.
- **The webcam needs a secure context**: `localhost` or `https`. A controller on
  another laptop runs the frontend locally against the remote backend
  (`CORS_ORIGINS` has the origin), or the frontend is served over HTTPS.

## Recorder: `exo_hand_command` in `policy/lerobot_robot_exo_hand`

A LeRobot `Teleoperator` whose `get_action()` is the last message on
`/hand/command` (`ExoHandLeader` is the pattern: same features, same freshness
and connection checks, no passive check). Before the first command it returns
`/hand/state`. Record with `--teleop.type=exo_hand_command --robot.passive=true`:
the robot must not publish the command a second time. The saved action can be
one frame (33 ms) behind the sent one. It works with any command source
(sliders, keys, mirror).

Rule for a recording: nobody arms the sliders in another tab.

## Tests (TDD, no camera, no ROS)

- `curl`: synthetic landmarks, straight finger ~0, bent finger = the known sum;
  the same hand translated, scaled and rotated gives the same bends.
- `calibration`: scaling, clipping, refusal of a degenerate range.
- `engage`: off until started; a hand -> `following`; dropout -> hold; return ->
  `following` at once; off -> nothing published.
- Socket with a fake tracker: a second client is refused, publish only on
  change, mock mode.
- `exo_hand_command`: returns the last command, the state before any command,
  stale data raises as in `ExoHandLeader`.
- Frontend: the panel against `MOCK=1`; no test of copy or layout.

## Done check (sim, then the real hand)

1. Sim or fake servos + backend + frontend: arm, Mirror on, calibrate. Open,
   fist and a pinch (thumb + index closed, the others open) show on the 3D hand;
   the controller can hold the thumb at ~0.5. A hand out of the view holds the
   hand; it follows again at once when the hand is back.
2. `lerobot-record` with `exo_hand_command` for two short episodes: the `action`
   column is the mirror's command.
3. Measure the loop rate with everything on one laptop (MediaPipe + camera
   streams + video encoding); below 30 Hz, record at 15 to 20 fps or use two
   machines.

Real hand, same code, only the launch file differs. Before anybody wears it
under mirror control: `servo_tool calibrate --write`, tune `contact_stop:` and
`hold_torque` (`hal-safety-design.md`), a first mirror run with the hand off the
wearer. **Do not change the contact stop after the recording starts**: the
policy learns against it.

## TODO, outside this spec

- Done, `iphone-camera-design.md`: the forehead iPhone is a ROS topic
  (`/head_camera/...`) and the second image key (`camera1`) in `ExoHand`. The
  mirror is the same with one policy camera or two.
- Recording console: episode buttons, shortcuts and recording status in the
  frontend. Starts with a read of the `lerobot==0.6.1` record loop to find the
  hook for the three flags.

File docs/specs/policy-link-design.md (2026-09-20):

# Policy link: LeRobot to ROS through rosbridge

How the learned policy reads the hand and the camera and moves the fingers.
Status: adapter implemented, smoke check passed against rosbridge on one machine. Date: 2026-09-19. This closes open question 1
of `../system-design.md`.

## Decisions

- All LeRobot parts run on the GPU laptop: `policy_server`, `RobotClient`,
  `lerobot-record` and our `ExoHand` adapter. The wearable ROS machine gets no
  new code, no `lerobot` and no torch.
- The adapter reaches ROS through the rosbridge WebSocket
  (`ws://<wearable-ip>:9090`) with `roslibpy`. Both launch files start
  rosbridge already, and `application/backend` uses the same path. No process
  imports both `rclpy` and `lerobot`.
- Link loss: the hand holds. The HAL keeps the last target with no time limit,
  so this is the present behaviour. There is no HAL watchdog. An open on
  timeout drops the object at each WiFi dropout.
- The adapter obeys the `/hand/command` rule of `physical_layer/CLAUDE.md`
  (publish only when there is something new): it has a deadband of `0.01`.
- The code goes in a new top-level folder, `policy/`.
- The `htn_auto` package is removed. It has no function in this layout.

## Scope

In: the `ExoHand` adapter with RGB and the finger state, its tests, a smoke
check against the sim, the removal of `htn_auto`, the CLAUDE.md updates.

Out:
- Depth. The first training version is RGB only. Depth needs a fixed 16-bit to
  8-bit conversion (LeRobot cameras are `H x W x 3` uint8) that is identical
  in recording and inference; `application/backend/app/depth.py` has the
  `compressedDepth` decode.
- Command arbitration (open question 7 of `../system-design.md`).
- The data collection method, the release signal, training.
- The emergency open and the force limit of `../system-design.md` (Safety).

## Data flow

```
wearable ROS machine                          GPU laptop
  HAL --/hand/state--------+
  camera --.../compressed--+--> rosbridge ==ws:9090==> ExoHand <-- RobotClient
  HAL <--/hand/command-----+                                          | gRPC, localhost
                                                                policy_server
```

- rosbridge pushes each message when it is published. The adapter keeps only
  the latest one. `get_observation()` reads the stored values and does not
  wait for the network.
- Each camera frame crosses WiFi (~30-50 KB JPEG at 15 fps, ~0.5-0.75 MB/s),
  also the frames that the policy does not use. If this is too much, set
  `throttle_rate` on the subscription; rosbridge then drops frames on the ROS
  machine.
- The action queue of `RobotClient` is on the GPU laptop. Each command crosses
  WiFi. A dropout stops the commands immediately; the queue does not drain
  into the hand.

## Components

### `policy/` - the adapter package

Plain Python (>= 3.12, a requirement of `lerobot`), outside the colcon build.
Dependencies: `lerobot` 0.6.1, `roslibpy`, `opencv-python`, `numpy`.

`lerobot` finds a third-party robot only as an installed distribution with a
name that starts with `lerobot_robot_`, and it looks for the class with the
name of the config class without `Config`. Thus:

```
policy/
  pyproject.toml                  distribution lerobot_robot_exo_hand
  lerobot_robot_exo_hand/
    __init__.py                   imports the two classes (registration)
    config_exo_hand.py            ExoHandConfig, registered as "exo_hand"
    exo_hand.py                   ExoHand
    convert.py                    pure functions, no lerobot import
  tests/
```

`ExoHandConfig` (a LeRobot `RobotConfig`):

| Field | Default | |
|---|---|---|
| `host` | - | IP of the wearable machine |
| `port` | `9090` | |
| `color_topic` | `/camera/color/image_raw/compressed` | never `image_raw`: rosbridge sends it as base64 JSON |
| `max_age_s` | `0.3` | oldest state or frame that `get_observation()` accepts |
| `command_tolerance` | `0.01` | deadband of `send_action()` |

`ExoHand` (a LeRobot `Robot`):
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

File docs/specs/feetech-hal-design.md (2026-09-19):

# Feetech servo backend for the HAL

Driver for the real hand: 5 Feetech ST series serial bus servos behind a
Waveshare Bus Servo Adapter (A). Status: implemented; scan, jog and feedback reads verified on one ST servo.
Date: 2026-09-19. This closes open question 6 of `../system-design.md`.

## Hardware facts

- The adapter is a CH343 USB to half-duplex UART bridge (`1a86:55d3`,
  `/dev/ttyACM0`). It has no MCU and no protocol of its own. The adapter
  switches the bus direction in hardware.
- The computer speaks the Feetech protocol directly to the servos, at
  1 000 000 baud (factory default of the ST series).
- ST series: 4096 steps per 360 degrees, little-endian 2-byte registers,
  position feedback. The servo has no command timeout.
- "253 servos" is the ID range of the bus (0..253; 254 is broadcast). The
  driver addresses servos by ID. The hand uses 5.
- New ST servos all have ID 1. Two servos with the same ID cannot share the
  bus.

## Scope

In: the protocol module, the HAL backend, a command-line servo tool, the YAML
and launch changes, removal of `SerialBackend`.

Out: the command watchdog and the emergency open of `../system-design.md`
(Safety). These belong in `hal_node.py` and apply to all backends. SC series
support (big-endian, 1024 steps) is also out.

## Components

All paths are in `physical_layer/ros2_ws/src/htn_control/htn_control/`.
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

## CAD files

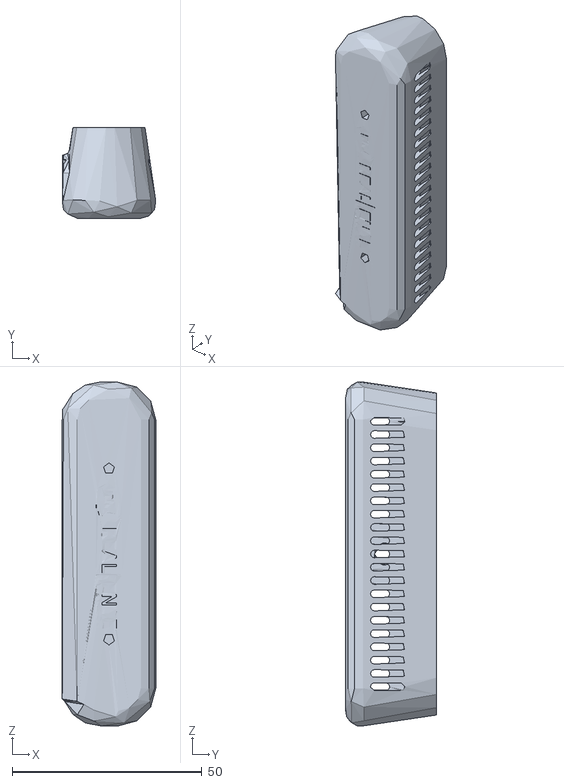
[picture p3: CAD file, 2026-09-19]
physical_layer/ros2_ws/src/htn_description/meshes/camera.stl
24.7 x 24.1 x 90.7

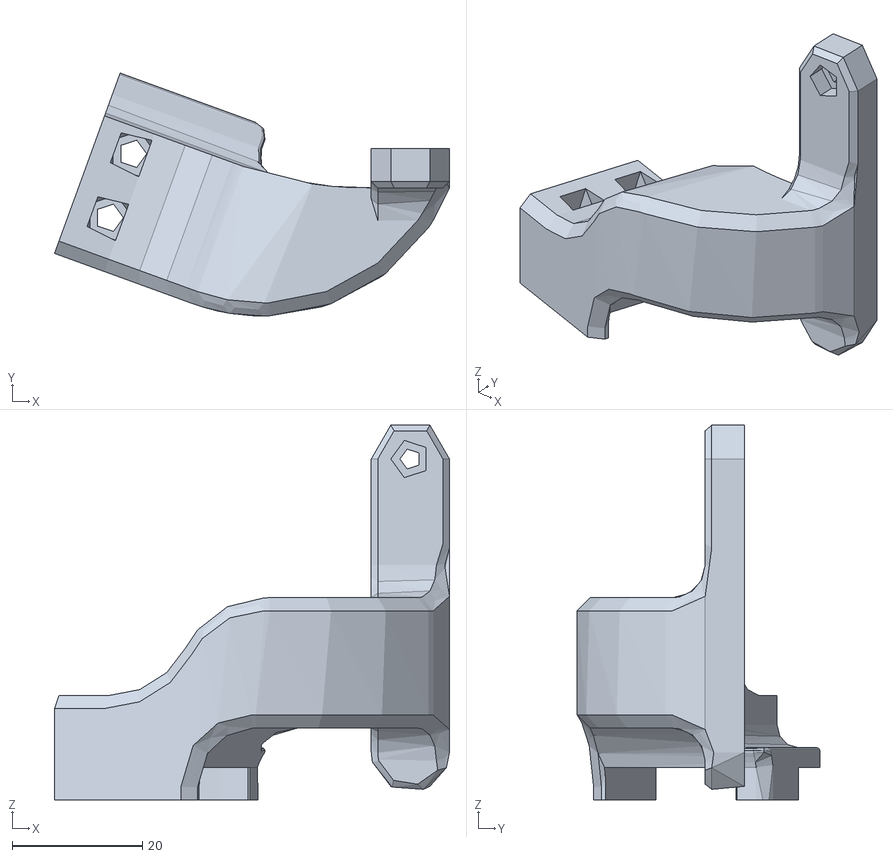
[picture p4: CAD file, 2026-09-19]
physical_layer/ros2_ws/src/htn_description/meshes/camera_mount.stl
60.6 x 37.3 x 57.5

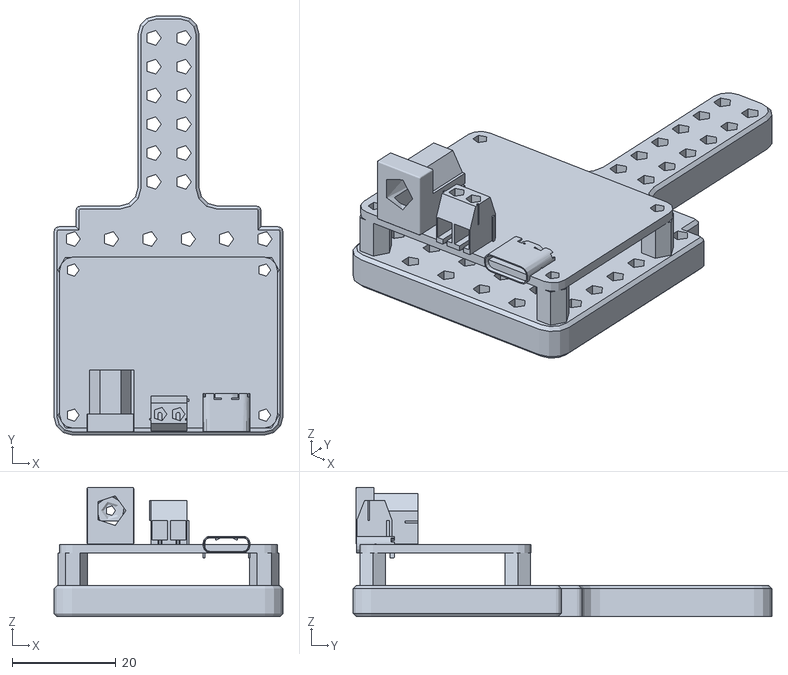
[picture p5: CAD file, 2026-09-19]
physical_layer/ros2_ws/src/htn_description/meshes/electronics.stl
44.2 x 80.9 x 24.9

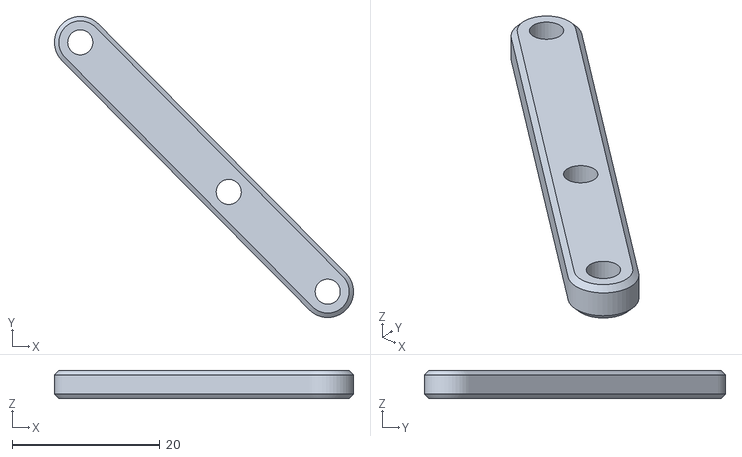
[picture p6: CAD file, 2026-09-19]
physical_layer/ros2_ws/src/htn_description/meshes/thumb_ternary.stl
40.4 x 40.7 x 3.80

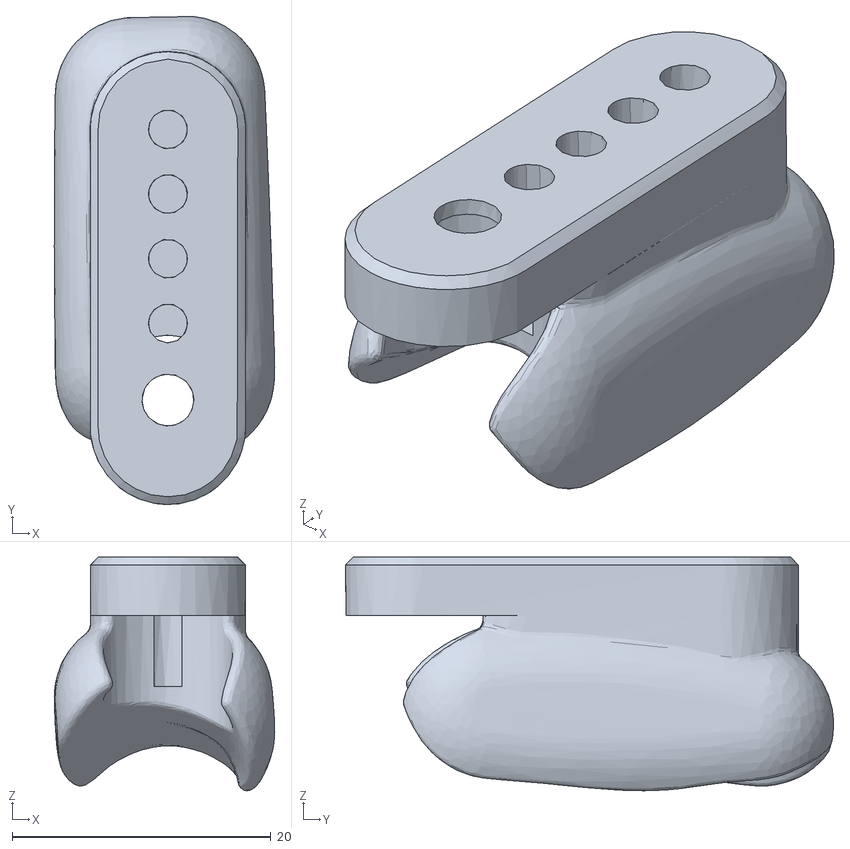
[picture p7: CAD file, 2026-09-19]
physical_layer/ros2_ws/src/htn_description/meshes/pinky_contact.stl
17.0 x 37.7 x 18.1

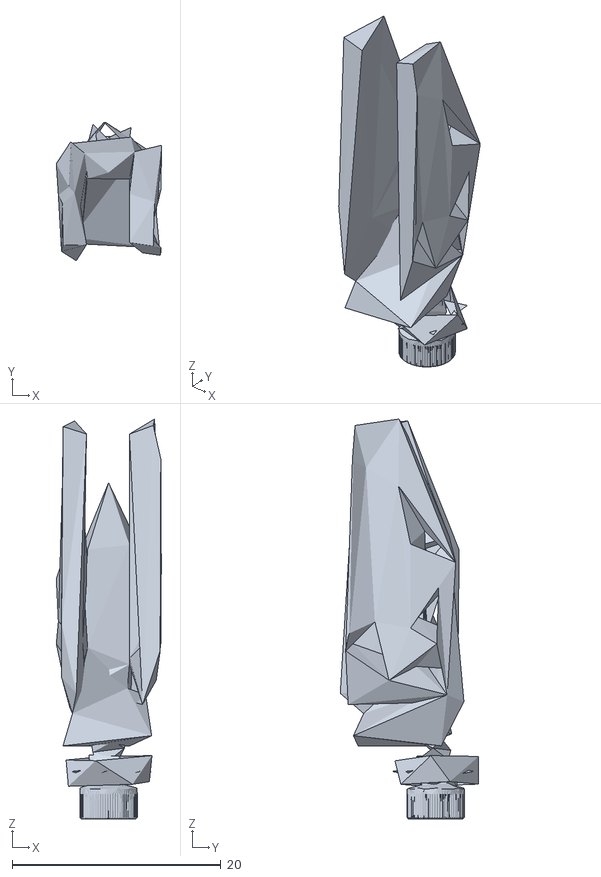
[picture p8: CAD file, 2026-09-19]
physical_layer/ros2_ws/src/htn_description/meshes/middle_adapter.stl
10.1 x 13.3 x 38.3

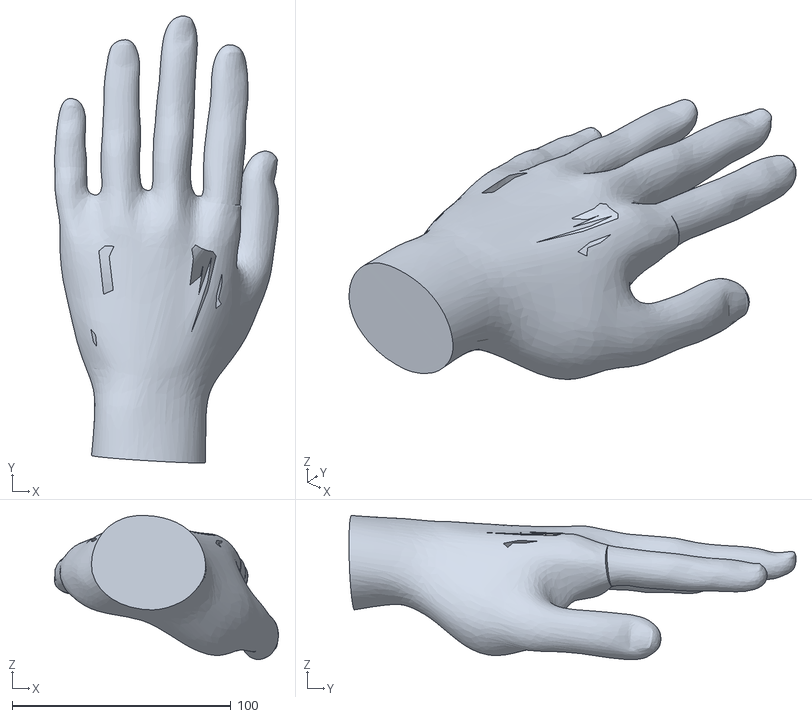
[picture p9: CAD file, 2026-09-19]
physical_layer/ros2_ws/src/htn_description/meshes/wearer.stl
102.5 x 204.5 x 66.0

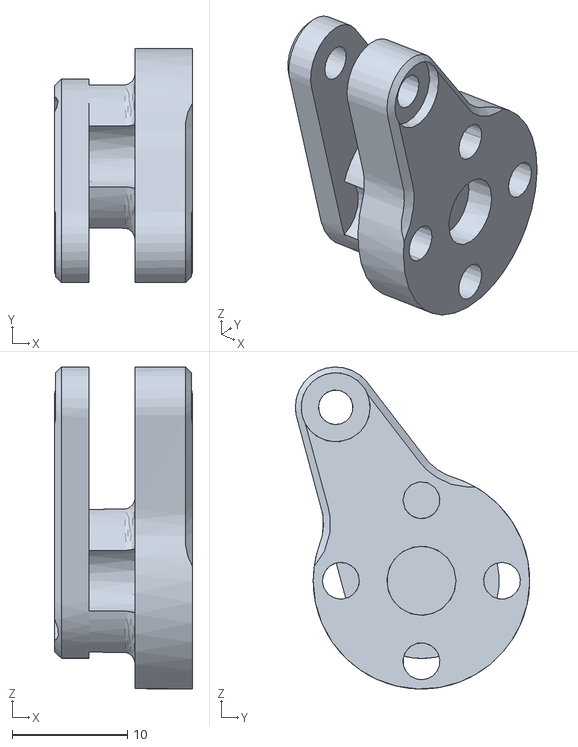
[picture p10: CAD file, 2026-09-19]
physical_layer/ros2_ws/src/htn_description/meshes/index_horn.stl
12.0 x 20.4 x 28.0

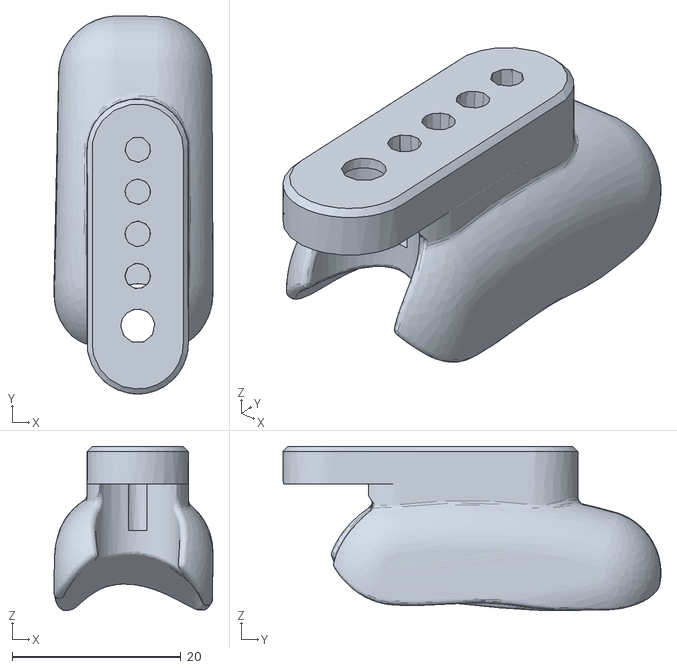
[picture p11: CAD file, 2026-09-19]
physical_layer/ros2_ws/src/htn_description/meshes/index_contact.stl
18.9 x 44.9 x 19.5

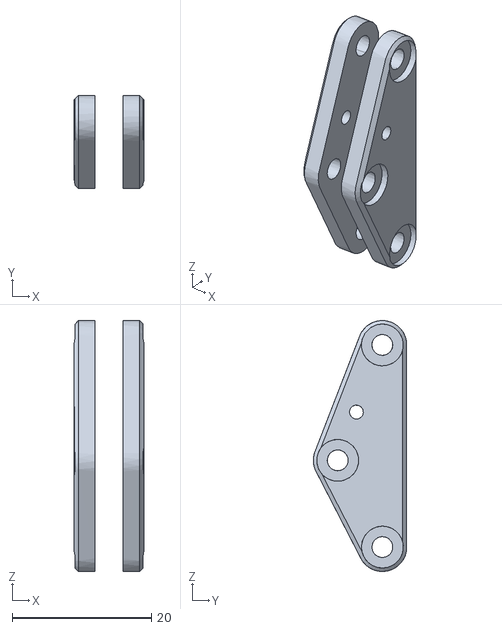
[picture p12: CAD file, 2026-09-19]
physical_layer/ros2_ws/src/htn_description/meshes/middle_triangle.stl
10.0 x 13.4 x 36.0

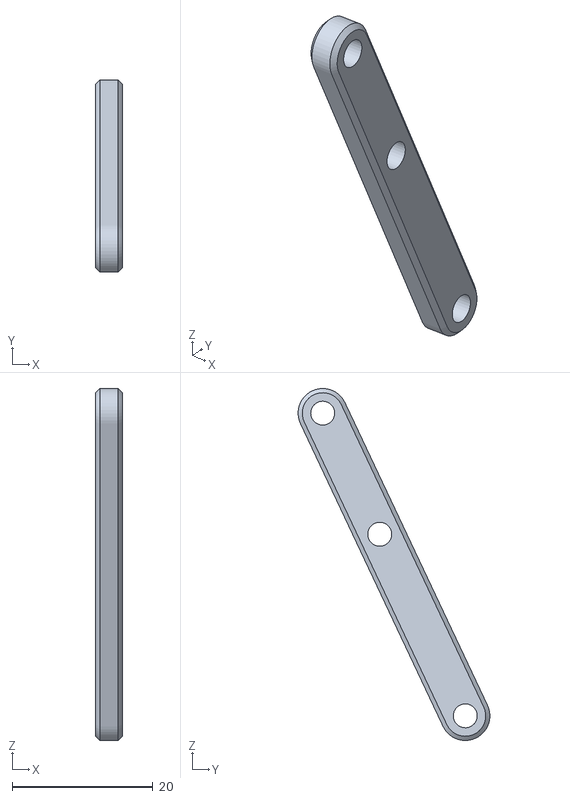
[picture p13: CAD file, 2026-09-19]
physical_layer/ros2_ws/src/htn_description/meshes/index_ternary.stl
3.80 x 27.2 x 50.0

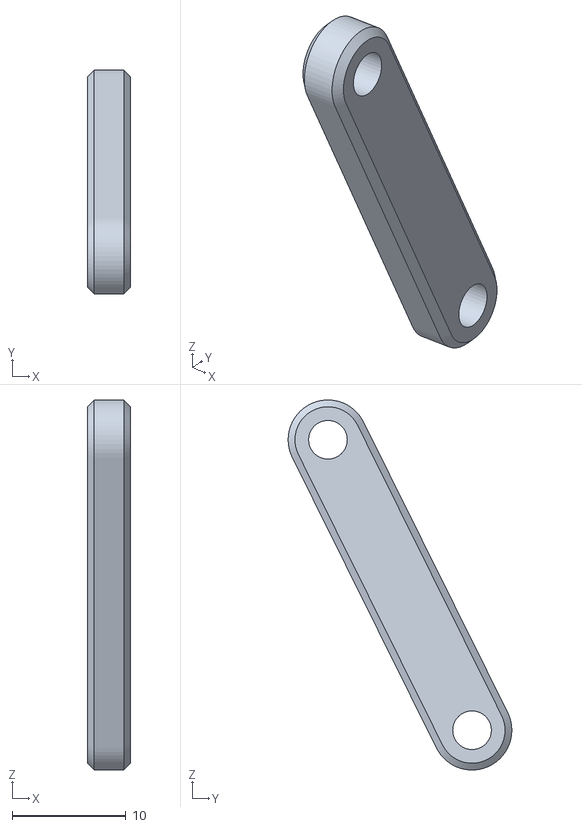
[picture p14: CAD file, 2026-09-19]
physical_layer/ros2_ws/src/htn_description/meshes/pinky_binary.stl
3.80 x 19.7 x 32.5

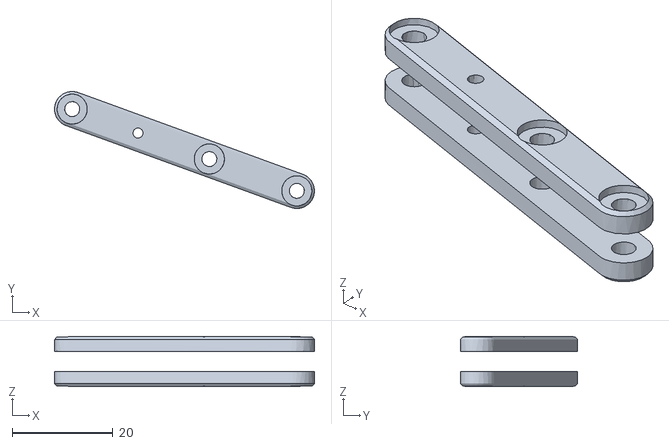
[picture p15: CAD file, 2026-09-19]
physical_layer/ros2_ws/src/htn_description/meshes/thumb_long.stl
51.7 x 23.3 x 10.0

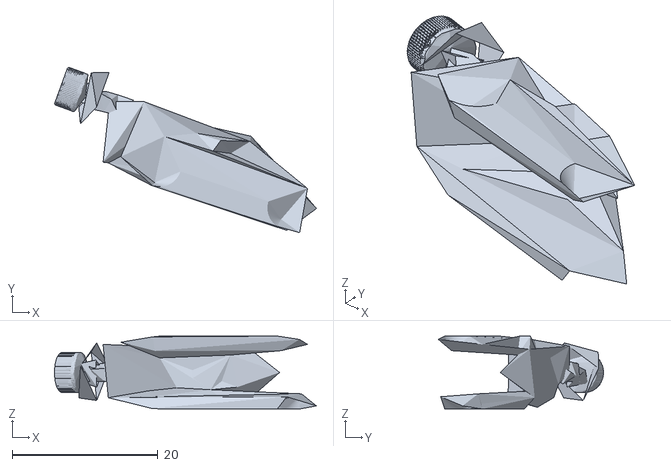
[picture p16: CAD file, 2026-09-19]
physical_layer/ros2_ws/src/htn_description/meshes/thumb_adapter.stl
36.0 x 22.7 x 10.0

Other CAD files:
physical_layer/ros2_ws/src/htn_description/meshes/index_adapter.stl
physical_layer/ros2_ws/src/htn_description/meshes/middle_binary.stl
physical_layer/ros2_ws/src/htn_description/meshes/pinky_triangle.stl
physical_layer/ros2_ws/src/htn_description/meshes/ring_adapter.stl
physical_layer/ros2_ws/src/htn_description/meshes/base.stl
physical_layer/ros2_ws/src/htn_description/meshes/index_binary.stl
physical_layer/ros2_ws/src/htn_description/meshes/index_long.stl
physical_layer/ros2_ws/src/htn_description/meshes/index_rod.stl
physical_layer/ros2_ws/src/htn_description/meshes/index_triangle.stl
physical_layer/ros2_ws/src/htn_description/meshes/middle_contact.stl
physical_layer/ros2_ws/src/htn_description/meshes/middle_horn.stl
physical_layer/ros2_ws/src/htn_description/meshes/middle_long.stl
physical_layer/ros2_ws/src/htn_description/meshes/middle_rod.stl
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

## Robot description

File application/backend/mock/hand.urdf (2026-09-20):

<?xml version="1.0" ?>
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
<robot name="htn_hand">
  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
  <link name="base_link">
    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
    <inertial>
      <mass value="0.63"/>
      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
    </inertial>
  </link>
  <link name="camera_link"/>
  <joint name="camera_mount_joint" type="fixed">
    <parent link="base_link"/>
    <child link="camera_link"/>
    <origin rpy="1.5708 0.0 1.5708" xyz="0.1358 0.0212 0.0465"/>
  </joint>
  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
  <link name="thumb_horn">
    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
    <inertial>
      <mass value="0.02"/>
      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
    </inertial>
  </link>
  <joint name="thumb_joint" type="revolute">
    <parent link="base_link"/>
    <child link="thumb_horn"/>
    <origin xyz="0.12789 -0.02186 -0.026760000000000003"/>
    <axis xyz="0 0 1"/>
    <limit effort="1.0" lower="0.0" upper="1.014" velocity="3.0"/>
    <dynamics damping="0.01" friction="0.0"/>
  </joint>
  <link name="thumb_rod">
    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
  </link>
  <joint name="thumb_rod_joint" type="continuous">
    <parent link="thumb_horn"/>
    <child link="thumb_rod"/>
    <origin xyz="0.011609999999999999 -0.012160000000000004 0.0"/>
    <axis xyz="0 0 1"/>
  </joint>
  <link name="thumb_triangle">
    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
  </link>
  <joint name="thumb_triangle_joint" type="continuous">
    <parent link="base_link"/>
    <child link="thumb_triangle"/>
    <origin xyz="0.13375 -0.00511 -0.026760000000000003"/>
    <axis xyz="0 0 1"/>
  </joint>
  <link name="thumb_ternary">
    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
  </link>
  <joint name="thumb_ternary_joint" type="continuous">
    <parent link="thumb_triangle"/>
    <child link="thumb_ternary"/>
    <origin xyz="0.02725 -0.00993 0.0"/>
    <axis xyz="0 0 1"/>
  </joint>
  <link name="thumb_long">
    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
  </link>
  <joint name="thumb_long_joint" type="continuous">
    <parent link="base_link"/>
    <child link="thumb_long"/>
    <origin xyz="0.12036 0.008369999999999999 -0.026760000000000003"/>
    <axis xyz="0 0 1"/>
  </joint>
  <link name="thumb_binary">
    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
  </link>
  <joint name="thumb_binary_joint" type="continuous">
    <parent link="thumb_long"/>
    <child link="thumb_binary"/>
    <origin xyz="0.04464 -0.01625 0.0"/>
    <axis xyz="0 0 1"/>
  </joint>
  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
  <link name="thumb_finger">
    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
  </link>
  <joint name="thumb_adapter_joint" type="continuous">
    <parent link="thumb_ternary"/>
    <child link="thumb_finger"/>
    <origin xyz="-0.03346 0.03372 0.0"/>
    <axis xyz="0 0 1"/>
  </joint>
  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
  <link name="index_horn">
    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
    <inertial>
      <mass value="0.02"/>
      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
    </inertial>
  </link>
  <joint name="index_joint" type="revolute">
    <parent link="base_link"/>
    <child link="index_horn"/>
    <origin xyz="0.078 0.03188 0.04446"/>
    <axis xyz="-1 0 0"/>
    <limit effort="1.0" lower="0.0" upper="1.2502" velocity="3.0"/>
    <dynamics damping="0.01" friction="0.0"/>
  </joint>
  <link name="index_rod">
    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
  </link>
  <joint name="index_rod_joint" type="continuous">
    <parent link="index_horn"/>
    <child link="index_rod"/>
    <origin xyz="0.0 -0.007449999999999999 0.01507"/>
    <axis xyz="1 0 0"/>
  </joint>
  <link name="index_triangle">
    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
  </link>
  <joint name="index_triangle_joint" type="continuous">
    <parent link="base_link"/>
    <child link="index_triangle"/>
    <origin xyz="0.078 0.04962 0.04424"/>
    <axis xyz="1 0 0"/>
  </joint>
  <link name="index_ternary">
    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
  </link>
  <joint name="index_ternary_joint" type="continuous">
    <parent link="index_triangle"/>
    <child link="index_ternary"/>
    <origin xyz="0.0 -9.99999999999801e-06 0.028999999999999995"/>
    <axis xyz="1 0 0"/>
  </joint>
  <link name="index_long">
    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
  </link>
  <joint name="index_long_joint" type="continuous">
    <parent link="base_link"/>
    <child link="index_long"/>
    <origin xyz="0.078 0.05771 0.02705"/>
    <axis xyz="1 0 0"/>
  </joint>
  <link name="index_binary">
    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
  </link>
  <joint name="index_binary_joint" type="continuous">
    <parent link="index_long"/>
    <child link="index_binary"/>
    <origin xyz="0.0 0.0 0.0475"/>
    <axis xyz="1 0 0"/>
  </joint>
  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
  <link name="index_finger">
    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
  </link>
  <joint name="index_adapter_joint" type="continuous">
    <parent link="index_ternary"/>
    <child link="index_finger"/>
    <origin xyz="0.0 0.020239999999999994 -0.04297"/>
    <axis xyz="1 0 0"/>
  </joint>
  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
  <link name="middle_horn">
    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
    <inertial>
      <mass value="0.02"/>
      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
    </inertial>
  </link>
  <joint name="middle_joint" type="revolute">
    <parent link="base_link"/>
    <child link="middle_horn"/>
    <origin xyz="0.055 0.00588 0.04446"/>
    <axis xyz="-1 0 0"/>
    <limit effort="1.0" lower="0.0" upper="1.2747" velocity="3.0"/>
    <dynamics damping="0.01" friction="0.0"/>
  </joint>
  <link name="middle_rod">
    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
  </link>
  <joint name="middle_rod_joint" type="continuous">
    <parent link="middle_horn"/>
    <child link="middle_rod"/>
    <origin xyz="0.0 -0.00745 0.01507"/>
    <axis xyz="1 0 0"/>
  </joint>
  <link name="middle_triangle">
    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
  </link>
  <joint name="middle_triangle_joint" type="continuous">
    <parent link="base_link"/>
    <child link="middle_triangle"/>
    <origin xyz="0.055 0.04962 0.04424"/>
    <axis xyz="1 0 0"/>
  </joint>
  <link name="middle_ternary">
    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
  </link>
  <joint name="middle_ternary_joint" type="continuous">
    <parent link="middle_triangle"/>
    <child link="middle_ternary"/>
    <origin xyz="0.0 -9.99999999999801e-06 0.028999999999999995"/>
    <axis xyz="1 0 0"/>
  </joint>
  <link name="middle_long">
    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
  </link>
  <joint name="middle_long_joint" type="continuous">
    <parent link="base_link"/>
    <child link="middle_long"/>
    <origin xyz="0.055 0.05771 0.02705"/>
    <axis xyz="1 0 0"/>
  </joint>
  <link name="middle_binary">
    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
  </link>
  <joint name="middle_binary_joint" type="continuous">
    <parent link="middle_long"/>
    <child link="middle_binary"/>
    <origin xyz="0.0 0.0 0.0475"/>
    <axis xyz="1 0 0"/>
  </joint>
  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
  <link name="middle_finger">
    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
  </link>
  <joint name="middle_adapter_joint" type="continuous">
    <parent link="middle_ternary"/>
    <child link="middle_finger"/>
    <origin xyz="0.0 0.020239999999999994 -0.04297"/>
    <axis xyz="1 0 0"/>
  </joint>
  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
  <link name="ring_horn">
    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
    <inertial>
      <mass value="0.02"/>
      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
    </inertial>
  </link>
  <joint name="ring_joint" type="revolute">
    <parent link="base_link"/>
    <child link="ring_horn"/>
    <origin xyz="0.033 0.00588 0.04446"/>
    <axis xyz="-1 0 0"/>
    <limit effort="1.0" lower="0.0" upper="1.2523" velocity="3.0"/>
    <dynamics damping="0.01" friction="0.0"/>
  </joint>
  <link name="ring_rod">
    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
  </link>
  <joint name="ring_rod_joint" type="continuous">
    <parent link="ring_horn"/>
    <child link="ring_rod"/>
    <origin xyz="0.0 -0.00745 0.01507"/>
    <axis xyz="1 0 0"/>
  </joint>
  <link name="ring_triangle">
    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
  </link>
  <joint name="ring_triangle_joint" type="continuous">
    <parent link="base_link"/>
    <child link="ring_triangle"/>
    <origin xyz="0.033 0.04962 0.04424"/>
    <axis xyz="1 0 0"/>
  </joint>
  <link name="ring_ternary">
    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
  </link>
  <joint name="ring_ternary_joint" type="continuous">
    <parent link="ring_triangle"/>
    <child link="ring_ternary"/>
    <origin xyz="0.0 -9.99999999999801e-06 0.028999999999999995"/>
    <axis xyz="1 0 0"/>
  </joint>
  <link name="ring_long">
    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
  </link>
  <joint name="ring_long_joint" type="continuous">
    <parent link="base_link"/>
    <child link="ring_long"/>
    <origin xyz="0.033 0.05771 0.02705"/>
    <axis xyz="1 0 0"/>
  </joint>
  <link name="ring_binary">
    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
  </link>
  <joint name="ring_binary_joint" type="continuous">
    <parent link="ring_long"/>
    <child link="ring_binary"/>
    <origin xyz="0.0 0.0 0.0475"/>
    <axis xyz="1 0 0"/>
  </joint>
  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
  <link name="ring_finger">
    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
  </link>
  <joint name="ring_adapter_joint" type="continuous">
    <parent link="ring_ternary"/>
    <child link="ring_finger"/>
    <origin xyz="0.0 0.020239999999999994 -0.04297"/>
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

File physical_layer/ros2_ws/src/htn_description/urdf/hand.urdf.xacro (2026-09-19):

<?xml version="1.0"?>
<robot name="htn_hand" xmlns:xacro="http://www.ros.org/wiki/xacro">

  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

  <xacro:arg name="params_file" default="$(find htn_description)/config/hand_params.yaml"/>
  <xacro:arg name="linkage_file" default="$(find htn_description)/config/linkage.yaml"/>
  <xacro:arg name="static_file" default="$(find htn_description)/config/static_parts.yaml"/>
  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
  <xacro:arg name="sim" default="none"/>
  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
  <xacro:arg name="controllers_file" default=""/>
  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
  <xacro:arg name="parts" default="full"/>

  <xacro:property name="params" value="${xacro.load_yaml('$(arg params_file)')}"/>
  <xacro:property name="linkage" value="${xacro.load_yaml('$(arg linkage_file)')['fingers']}"/>
  <xacro:property name="static" value="${xacro.load_yaml('$(arg static_file)')}"/>
  <xacro:property name="joint_params" value="${params['joint']}"/>
  <xacro:property name="full" value="${'$(arg parts)' == 'full'}"/>
  <xacro:property name="MESHES" value="package://htn_description/meshes"/>

  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
  <xacro:property name="limit_margin" value="${0.05 if '$(arg sim)' == 'gazebo' else 0.0}"/>

  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
  <xacro:property name="at" value="${lambda l, name, origin=None: ' '.join(str(v / 1000.0) for v in ( lambda p, o, c: ((c, p[0] - o[0], p[1] - o[1]) if l['axis'] == 'x' else (p[0] - o[0], p[1] - o[1], c)))( l['pivots'][name], l['pivots'][origin] if origin else (0.0, 0.0), 0.0 if origin else l['plane']))}"/>
  <xacro:property name="axis_of" value="${lambda l, sign=1: '%g 0 0' % sign if l['axis'] == 'x' else '0 0 %g' % sign}"/>

  <xacro:property name="look" value="${params['appearance']}"/>
  <xacro:macro name="colour" params="name">
    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
  </xacro:macro>
  <xacro:colour name="body"/>
  <xacro:colour name="servo"/>
  <xacro:colour name="finger"/>
  <xacro:colour name="accent"/>
  <xacro:colour name="pad"/>
  <xacro:colour name="wearer"/>
  <xacro:colour name="camera"/>
  <xacro:colour name="pcb"/>

  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
  <xacro:macro name="part" params="mesh material pivot:='0 0 0'">
    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
  </xacro:macro>

  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
  <xacro:macro name="cube_inertial" params="m side">
    <inertial>
      <mass value="${m}"/>
      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
    </inertial>
  </xacro:macro>

  <link name="base_link">
    <xacro:part mesh="base" material="body"/>
    <xacro:if value="${full}">
      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
      <xacro:part mesh="wearer" material="wearer"/>
      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
      <xacro:part mesh="camera" material="camera"/>
      <xacro:part mesh="camera_mount" material="body"/>
      <xacro:part mesh="electronics" material="pcb"/>
    </xacro:if>
    <xacro:cube_inertial m="${params['base']['mass']}" side="0.10"/>
  </link>

  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
  <xacro:macro name="passive" params="finger role l parent pivot origin material">
    <link name="${finger}_${role}">
      <xacro:part mesh="${finger}_${role}" material="${material}" pivot="${at(l, pivot)}"/>
    </link>
    <joint name="${finger}_${role}_joint" type="continuous">
      <parent link="${parent}"/>
      <child link="${finger}_${role}"/>
      <origin xyz="${at(l, pivot, origin)}"/>
      <axis xyz="${axis_of(l)}"/>
    </joint>
  </xacro:macro>

  <xacro:macro name="finger" params="name">
    <xacro:property name="f" value="${params['fingers'][name]}"/>
    <xacro:property name="l" value="${linkage[name]}"/>

    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
    <link name="${name}_horn">
      <xacro:part mesh="${name}_horn" material="servo" pivot="${at(l, 'G0')}"/>
      <xacro:cube_inertial m="${f['mass']}" side="0.02"/>
    </link>
    <joint name="${name}_joint" type="revolute">
      <parent link="base_link"/>
      <child link="${name}_horn"/>
      <origin xyz="${at(l, 'G0')}"/>
      <axis xyz="${axis_of(l, l['closing'])}"/>
      <limit lower="${f['min_angle'] - limit_margin}" upper="${f['max_angle'] + limit_margin}" effort="${joint_params['max_effort']}" velocity="${joint_params['max_velocity']}"/>
      <dynamics damping="${joint_params['damping']}" friction="${joint_params['friction']}"/>
    </joint>
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

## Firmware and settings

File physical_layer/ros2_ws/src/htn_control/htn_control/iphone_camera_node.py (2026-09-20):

"""Head camera: the forehead iPhone (Record3D app, USB) as a ROS camera.

    /head_camera/color/image_raw/compressed   sensor_msgs/CompressedImage, jpeg
    /head_camera/color/camera_info
    /head_camera/aligned_depth_to_color/image_raw/compressedDepth   16UC1 millimetres, the LiDAR,
        turned and sized as the colour picture (so camera_info is the same one). Not for the
        policy: for the console's object map when the phone is the only camera.

Design: docs/specs/iphone-camera-design.md. The record3d library runs in a child
process (iphone_worker.py says why); this node turns, shrinks, encodes and
publishes each frame, and starts a new worker when one ends. The rotation and the
size are part of a recorded dataset: do not change them after the first recording.
"""
import multiprocessing
import threading
import time

import cv2
import numpy as np
import rclpy
from rclpy.executors import ExternalShutdownException
from rclpy.node import Node
from sensor_msgs.msg import CameraInfo, CompressedImage

from htn_control import iphone_worker

FRAME_ID = 'head_camera_color_optical_frame'  # no TF: the head is not attached to the hand
ROTATIONS = {0: None, 90: cv2.ROTATE_90_CLOCKWISE, 180: cv2.ROTATE_180, 270: cv2.ROTATE_90_COUNTERCLOCKWISE}
RETRY_MIN_S, RETRY_MAX_S = 1.0, 8.0
START_TIMEOUT_S = 12.0       # spawn an interpreter, ask usbmuxd for devices, connect
# A connection that stays silent is dead on the phone's side (the app streams to its newest
# client and never closes the old one). Reconnecting is safe - killing the worker really
# closes the socket - and the app resumes at once, so do not sit on a silent one.
FIRST_FRAME_TIMEOUT_S = 5.0
FRAME_TIMEOUT_S = 3.0


def prepare(rgb, rotation, width, height):
    """The sensor's picture -> the published one: turned clockwise by `rotation`, then width x height."""
    turn = ROTATIONS[rotation]
    turned = rgb if turn is None else cv2.rotate(rgb, turn)
    return cv2.resize(turned, (width, height), interpolation=cv2.INTER_AREA)


def prepare_depth(depth_m, rotation, width, height):
    """The LiDAR's metres -> uint16 millimetres on the pixels of prepare()'s picture. 0 = no reading.
    Nearest neighbour: a hole stays a hole and is not smeared into the depths next to it."""
    mm = np.nan_to_num(depth_m * 1000.0, nan=0.0, posinf=0.0, neginf=0.0)
    mm = np.clip(mm, 0.0, 65535.0).round().astype(np.uint16)
    turn = ROTATIONS[rotation]
    turned = mm if turn is None else cv2.rotate(mm, turn)
    return cv2.resize(turned, (width, height), interpolation=cv2.INTER_NEAREST)


def compressed_depth(mm):
    """The data of a `16UC1; compressedDepth png` message, as compressed_depth_image_transport makes
    it: its 12-byte header (format, two depth parameters: unused for 16UC1) and then the PNG."""
    ok, png = cv2.imencode('.png', mm, (cv2.IMWRITE_PNG_COMPRESSION, 1))
    return bytes(12) + png.tobytes() if ok else None


def camera_matrix(k, shape, rotation, width, height):
    """(fx, fy, cx, cy) of the sensor's picture (`shape` = its rows, columns) -> the same of the
    picture that prepare() makes of it. Pixel centres are whole numbers."""
    fx, fy, cx, cy = k
    rows, columns = shape[:2]
    if rotation == 90:
        fx, fy, cx, cy, rows, columns = fy, fx, rows - 1 - cy, cx, columns, rows
    elif rotation == 180:
        cx, cy = columns - 1 - cx, rows - 1 - cy
    elif rotation == 270:
        fx, fy, cx, cy, rows, columns = fy, fx, cy, columns - 1 - cx, columns, rows
    sx, sy = width / columns, height / rows
    return fx * sx, fy * sy, (cx + 0.5) * sx - 0.5, (cy + 0.5) * sy - 0.5


def supervise(session, log, stopped, sleep=time.sleep):
    """Run `session()` again and again until `stopped()`. A session returns (why it ended, whether
    it had streamed). Backoff 1 .. 8 s; the reason is logged once per change, not once per try."""
    delay, last = RETRY_MIN_S, None
    while not stopped():
        reason, streamed = session()
        if streamed:
            delay, last = RETRY_MIN_S, None  # it worked a moment ago: retry promptly, and say why it ended
        if reason != last and not stopped():
            log(reason)
            last = reason
        sleep(delay)
        delay = min(delay * 2, RETRY_MAX_S)


class IphoneCamera(Node):
    make_stream = staticmethod(iphone_worker.record3d_stream)  # the tests put a fake phone here

    def __init__(self):
        super().__init__('iphone_camera')
        self.rotation = self.declare_parameter('rotation', 270).value
        self.width = self.declare_parameter('width', 640).value
        self.height = self.declare_parameter('height', 480).value
        self.max_fps = self.declare_parameter('max_fps', 15.0).value
        self.jpeg_quality = self.declare_parameter('jpeg_quality', 80).value
        self.depth = self.declare_parameter('depth', True).value
        if self.rotation not in ROTATIONS:
            raise ValueError(f'rotation must be one of {sorted(ROTATIONS)}, got {self.rotation}')
        self.image_pub = self.create_publisher(CompressedImage, '/head_camera/color/image_raw/compressed', 1)
        self.info_pub = self.create_publisher(CameraInfo, '/head_camera/color/camera_info', 1)
        self.depth_pub = self.create_publisher(
            CompressedImage, '/head_camera/aligned_depth_to_color/image_raw/compressedDepth', 1)
        self.closing = threading.Event()
        self.thread = threading.Thread(target=supervise, daemon=True, args=(
            self.session, lambda reason: self.get_logger().warning(f'{reason}. Trying again by itself.'),
            self.closing.is_set, self.closing.wait))
        self.thread.start()

    def session(self):
        """One worker from start to end. Returns (why it ended, whether it had streamed)."""
        context = multiprocessing.get_context('spawn')  # never fork a process that has ROS threads
        receiver, sender = context.Pipe(duplex=False)
        worker = context.Process(target=iphone_worker.run, args=(sender, self.max_fps, self.make_stream, self.depth),
                                 name='record3d-usb', daemon=True)
        worker.start()
        sender.close()
        # Frames can overtake the "connected" notice (the library starts reading before
        # connect() returns), so every message is handled in whatever order it arrives.
        timeout, problem, streamed = START_TIMEOUT_S, iphone_worker.USB_STUCK, False
        try:
            while not self.closing.is_set():
                if not receiver.poll(timeout):
                    return problem, streamed
                message = receiver.recv()
                if message[0] == 'frame':
                    if not streamed:
                        self.get_logger().info(f'iPhone streaming, {message[1].shape[1]} x {message[1].shape[0]}')
                    timeout, problem, streamed = FRAME_TIMEOUT_S, iphone_worker.USB_SILENT, True
                    self.publish(*message[1:])
                elif message[0] == 'connected' and not streamed:
                    timeout, problem = FIRST_FRAME_TIMEOUT_S, iphone_worker.USB_SILENT
                elif message[0] == 'error':
                    return message[1], streamed
                elif message[0] == 'stopped':
                    return iphone_worker.STOPPED, streamed
            return 'shutting down', streamed
        except (EOFError, OSError):
            return 'the worker process died', streamed
        finally:
            worker.kill()  # the one disconnect that really closes the socket to the phone
            worker.join(3.0)
            receiver.close()

    def publish(self, rgb, k, depth_m=None):
        picture = prepare(rgb, self.rotation, self.width, self.height)
        ok, jpeg = cv2.imencode('.jpg', cv2.cvtColor(picture, cv2.COLOR_RGB2BGR),
                                (cv2.IMWRITE_JPEG_QUALITY, self.jpeg_quality))
        if not ok:
            return
        image = CompressedImage(format='jpeg', data=jpeg.tobytes())
        image.header.stamp = self.get_clock().now().to_msg()  # the time the frame arrived
        image.header.frame_id = FRAME_ID
        fx, fy, cx, cy = camera_matrix(k, rgb.shape, self.rotation, self.width, self.height)
        info = CameraInfo(header=image.header, width=self.width, height=self.height,
                          distortion_model='plumb_bob', d=[0.0] * 5,
                          k=[fx, 0.0, cx, 0.0, fy, cy, 0.0, 0.0, 1.0],
                          r=np.eye(3).flatten().tolist(),
                          p=[fx, 0.0, cx, 0.0, 0.0, fy, cy, 0.0, 0.0, 0.0, 1.0, 0.0])
        self.image_pub.publish(image)
        self.info_pub.publish(info)
        if depth_m is not None:
            data = compressed_depth(prepare_depth(depth_m, self.rotation, self.width, self.height))
            if data is not None:
                self.depth_pub.publish(CompressedImage(header=image.header, format='16UC1; compressedDepth png',
                                                       data=data))

    def close(self):
        self.closing.set()
        self.thread.join(5.0)  # the session kills its worker on the way out


def main():
    rclpy.init()
    node = IphoneCamera()
    try:
        rclpy.spin(node)
    except (KeyboardInterrupt, ExternalShutdownException):
        pass
    finally:
        node.close()
        node.destroy_node()
        rclpy.try_shutdown()


if __name__ == '__main__':
    main()

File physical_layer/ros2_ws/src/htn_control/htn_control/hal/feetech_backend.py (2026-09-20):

from htn_control.hal import feetech
from htn_control.hal.base import HandBackend
from htn_control.hal.feetech import FeetechBus, from_sign_magnitude, from_u16, u16
from htn_control.hand_config import FINGERS


def to_step(position, open_step, closed_step):
    return round(open_step + position * (closed_step - open_step))


def to_norm(step, open_step, closed_step):
    return (step - open_step) / (closed_step - open_step)


def clamp_step(step):
    return min(max(step, 0), 4095)


class FeetechBackend(HandBackend):
    """Feetech ST series bus servos behind a USB bus adapter (no MCU).

    Per-servo id and calibration come from the `servos` section of
    hand_params.yaml: open_step / closed_step are the servo positions
    (0..4095) at finger fully open / closed; closed_step < open_step is fine
    for a servo mounted the other way round.
    """

    def __init__(self, node, hand_params):
        super().__init__(node, hand_params)
        servos = hand_params['servos']
        self.ids = [servos[f]['id'] for f in FINGERS]
        self.open_step = [servos[f]['open_step'] for f in FINGERS]
        self.closed_step = [servos[f]['closed_step'] for f in FINGERS]
        self.measured = [None] * len(FINGERS)
        self.torque_limit = servos['torque_limit']
        self.hold_torque = servos.get('hold_torque', self.torque_limit)

        port = node.declare_parameter('serial_port', '/dev/ttyACM0').value
        baud = node.declare_parameter('baud_rate', 1_000_000).value
        # Unit 100 steps/s^2, 0 = no limit
        # The servo's own ramp, in 100 steps/s^2 (254 = the most). The HAL's sweep already eases every
        # move in and out; at 50 the servo took another 0.3 s to reach its speed, and coasted as long
        # past a goal that stopped - a quick key stroke was a wobble, not a stroke.
        acceleration = node.declare_parameter('servo_acceleration', 254).value
        # False is for bench tests with part of the servos; the hand needs all 5
        require_all = node.declare_parameter('require_all_servos', True).value
        self.bus = FeetechBus(port, baud)

        # `enabled: false` = not calibrated yet: that finger never gets torque or a goal, whatever
        # is commanded. It is treated like a servo that is not there (it reports its command).
        self.enabled = [servos[f].get('enabled', True) for f in FINGERS]
        self.present = [enabled and self.bus.ping(i) for i, enabled in zip(self.ids, self.enabled)]
        for finger, servo_id, present, enabled in zip(FINGERS, self.ids, self.present, self.enabled):
            if present:
                continue
            if not enabled:
                node.get_logger().warning(f'{finger} servo (id {servo_id}) is disabled in hand_params.yaml '
                                          f'(not calibrated): it will not be driven')
                continue
            if require_all:
                self.bus.close()
                raise RuntimeError(f'No answer from {finger} servo (id {servo_id}) on {port}')
            node.get_logger().warning(f'No {finger} servo (id {servo_id}), running without it')
        self.active_ids = [i for i, present in zip(self.ids, self.present) if present]
        # A finger without a servo reports its command. Before the first command that is "open":
        # it must not stay None, or the HAL (which drives nothing before it has a whole measured
        # pose) would wait for ever and the fingers that ARE there would never get torque.
        self.measured = [None if present else 0.0 for present in self.present]
        self.current = [0.0] * len(FINGERS)  # mA, absolute
        # The torque limit is RAM: set it before the servos get torque. The torque itself stays
        # OFF here: the HAL turns it on through set_torque() once it knows the measured pose, with
        # that pose as the goal. Enabling it here drove every finger to whatever goal the servo
        # still held, at full torque, before anything had looked at where the fingers are.
        for servo_id in self.active_ids:
            self.bus.write(servo_id, feetech.ADDR_TORQUE_ENABLE, [0])
            self.bus.write(servo_id, feetech.ADDR_TORQUE_LIMIT, u16(self.torque_limit))
            self.bus.write(servo_id, feetech.ADDR_ACCELERATION, [acceleration])
        node.get_logger().info(f'Feetech backend on {port} @ {baud}, ids {self.active_ids}')

    has_torque_limit = True

    def set_torque_limit(self, finger, blocked):
        if self.present[finger]:
            self.bus.write(self.ids[finger], feetech.ADDR_TORQUE_LIMIT,
                           u16(self.hold_torque if blocked else self.torque_limit))

    def write(self, positions):
        for n, position in enumerate(positions):
            if not self.present[n]:
                self.measured[n] = position
        self.bus.sync_write(feetech.ADDR_GOAL_POSITION, {
            i: u16(clamp_step(to_step(p, o, c)))  # a pose outside 0..1 is legal (start-up), the encoder range is not
            for i, p, o, c, present in zip(self.ids, positions, self.open_step,
                                           self.closed_step, self.present) if present})

    def read(self):
        # position .. current is one block (15 bytes), like the vendor SDK reads it
        replies = self.bus.sync_read(feetech.ADDR_PRESENT_POSITION, 15, self.active_ids)
        log = self.node.get_logger()
        for n, (finger, servo_id) in enumerate(zip(FINGERS, self.ids)):
            if not self.present[n]:
                continue
            if servo_id not in replies:
                log.warning(f'No position from {finger} servo (id {servo_id})',
                            throttle_duration_sec=2.0)
                continue
            self.measured[n] = to_norm(
                from_u16(replies[servo_id][:2]), self.open_step[n], self.closed_step[n])
            self.current[n] = abs(from_sign_magnitude(replies[servo_id][13:15], 15)) * feetech.CURRENT_MA
            if self.bus.errors.get(servo_id):
                log.warning(f'{finger} servo (id {servo_id}) reports error '
                            f'0x{self.bus.errors[servo_id]:02x}', throttle_duration_sec=2.0)
        return None if None in self.measured else list(self.measured)

    def read_current(self):
        return list(self.current)

    def set_torque(self, enabled, hold=None):
        if enabled and hold is not None:
            # Goal first, torque second: a servo that gets torque with a stale
            # goal drives there at once, through whatever the fingers hold.
            self.write(hold)
        self.bus.sync_write(feetech.ADDR_TORQUE_ENABLE,
                            {i: [1 if enabled else 0] for i in self.active_ids})

    def close(self):
        try:
            self.bus.sync_write(feetech.ADDR_TORQUE_ENABLE, {i: [0] for i in self.active_ids})
        finally:
            self.bus.close()

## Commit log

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2026-09-19 Feetech ST bus servo backend for the HAL
    Replaces SerialBackend (ASCII protocol for firmware that does not exist):
    the Waveshare bus servo adapter is a plain USB-UART bridge, so the HAL
    speaks the Feetech protocol directly. Adds servo_tool (scan, set-id, jog)
    and the design spec in docs/specs/.
    [base.py, feetech.py, feetech_backend.py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]
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2026-09-19 Policy adapter: pure conversions between rosbridge and LeRobot dicts
    First slice of docs/specs/policy-link-design.md: JPEG -> RGB, state ->
    observation, action -> clamped command (rejects NaN), the publish deadband
    and the freshness check. No lerobot or roslibpy import, so the tests run
    anywhere. The spec records the lerobot 0.6.1 facts that fix the package
    layout (lerobot_robot_ prefix, Python >= 3.12).
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2026-09-19 HAL: use logger.warning(), warn() crashes the node on Kilted
    On Kilted warn() is a deprecated wrapper, and rclpy keys its per-call-site
    filter context on the wrapper frame, so every warn() in a node shares one
    context. A plain warn() followed by a throttled one raised ValueError and
    killed the HAL at start. The backend test uses one real logger per node so
    it catches this.
    [feetech_backend.py, hal_node.py, test_feetech.py]
2026-09-19 iPhone USB: run record3d in a killable child process
    Fixes the 'inverted' connect (Connect errors until you press stop on the
    phone): record3d's disconnect() never closes its usbmux socket, so after the
    client gave up on a silent connection the phone kept a ghost client and
    refused the next one - it serves a single client. Also fixes the backend
    freezing for good and surviving Ctrl-C as an orphan on port 8000:
    disconnect() holds the library lock while calling into Python and deadlocks
    against the GIL when the stream ends at the same moment.
    The library now lives in app/usb_worker.py, a spawned child process; ending a
    session kills it, which closes the socket for real. Once connected the cli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
2026-09-19 iPhone USB: correct the connect order in every message, retry faster
    Record3D only listens for the USB client while idle; the record button then
    starts the stream (official README order). Our messages said to press the
    button first, which makes the app refuse the connection - the reported
    'Connect errors until I press stop on the phone'. Reworded the refusal and the
    waiting hint, documented the order, and capped USB retries at 2 s so stopping
    the recording reconnects almost immediately.
2026-09-19 iPhone USB: reconnect a silent connection, messages match the measured phone behaviour
    Probing usbmux port 1337 on the real phone showed the opposite of the library
    README: the port is closed while Record3D is idle and opens when the red
    record button is pressed, and the app streams to its NEWEST connection while
    silently abandoning the older one. So a connection that stays silent is dead,
    and holding it forever (previous commit) left the panel stuck on 'waiting for
    frames' - seen for two minutes on the real device. Now: refused = app idle,
    retry every 2 s; connected but silent for 5 s = reconnect (safe, the worker
    kill really closes the socket). The last explanation stays visible through
    re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
2026-09-19 iPhone USB hints: the stream runs while Record3D is NOT recording
    Confirmed by the user on the device: the red record button pauses the USB
    stream and stopping it resumes it - every hint said the opposite. Swapped the
    refusal, silent-connection and card texts, and the note in CONTRACT.md.
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2026-09-19 Backdrive (passive) mode for recording demonstrations
    The piece docs/specs/data-collection-design.md left for 'another person': the
    HAL can cut the torque so a person moves the fingers while /hand/state keeps
    reporting the encoders - the input for the LeRobot recorder.
    - HAL: service /hand/set_passive (std_srvs/SetBool), latched /hand/passive,
    param/launch arg passive:=true. While passive, commands are ignored and
    setpoint = target = measured, so leaving the mode holds the current pose; the
    pose is published once on /hand/command so every controller starts from it.
    - HandBackend.set_torque(enabled, hold): Feetech writes the goal BEFORE the
    torque, so the hand never snaps to a stale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
    [base.py, feetech_backend.py, hal_node.py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]
2026-09-19 Passive mode tests: wait for the fake bus before reading its registers
    Sync writes get no reply, so the assertions could run before the fake servo
    thread had handled them (4 failures in 12 runs). A read is a barrier.
    30 runs clean.
    [test_passive.py]
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2026-09-19 The hand as built: CAD meshes and the real finger linkages
    The Fusion export in ~/Downloads/URDF_description has all 49 parts as STL but
    only 2 joints (the ones defined in Fusion), so it could not replace the hand as
    it is. The mechanism is recovered from the geometry instead:
    - htn_description/tools/cad_to_linkage.py finds the pivots from the pin holes
    parts share (checked against the 2 exported joints: equal to 0.003 mm).
    Every finger is the same 1-DOF chain of three four-bars. It writes
    config/linkage.yaml and decimated meshes (32 MB -> 5 MB); the mannequin hand
    inside the CAD base body becomes its own 'wearer' mesh.
    - htn_control/linkage.py solves the chain (circle intersections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
    [base.stl, hand.urdf, hand.urdf.xacro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]
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2026-09-19 Policy: recorder and policy check the HAL mode on /hand/passive
    The leader refuses to record unless the HAL reports torque off: with
    torque the fingers do not move and lerobot-record stores constant labels
    with no error. ExoHand refuses to command a passive HAL, which ignores
    /hand/command, so a policy would run while the hand stands still.
    require_passive=false is for recordings where something else moves the hand.
2026-09-19 Responsiveness: cancel Gazebo's servo lag, 60 Hz state to the viewer
    Measured a full close (0 -> 1) end to end, as the browser sees it:
    first motion 100-130 ms -> 50 ms, 50% 429 -> ~280 ms, 90% 627 -> ~505 ms
    (the HAL's safety ramp alone is 250 / 450 ms).
    - SimBackend commands ahead of the setpoint by lag * velocity. gz_ros2_control
    0.7.x makes every position joint a 100 ms first-order lag (0.1 * error *
    100 Hz) and the gain cannot be set: the plugin creates its node before it
    loads the parameter file (its log always says 'set to: 0.1').
    - Web: /ws/state at 60 Hz with a 16 ms rosbridge throttle (was 30 Hz / 33 ms),
    viewer smoothing 50 -> 22 ms, slider commands every 25 ms (was 50)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
    [sim_backend.py]
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2026-09-19 Fix the 3D hand jumping through one intermediate pose; Python nodes off sim time
    Reported twice as stutter / 'moves to an intermediate position, then to the
    target, extremely laggy'. My earlier measurements looked at /hand/state; the
    viewer animates from /joint_states. Measured that: during a full move the horn
    angle reaching the viewer changed in 2 of 32 frames, 333 ms apart
    (0 -> 0.18 -> 1.05 rad).
    Cause, introduced with the linkage hand: /joint_states has two publishers, and
    linkage_publisher's passive-joint message follows every driven-joint message.
    rosbridge's throttle keeps the latest message per period, so the web backend
    was handed almost only passive joints. linkage_publisher now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
    [linkage_publisher.py, test_linkage.py]
2026-09-19 Docs: backdrive does not work with these servos
    Result of the test on the real thumb: too stiff with the torque off, and
    four versions of an encoder-only active backdrive did not give a light
    start. The specs say so, and that the action source must change to
    commands with the torque on. The experiment code is not kept.
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2026-09-19 Real hand: no blind drive at start, contact stop, servo_tool calibrate
    Built to docs/specs/hal-safety-design.md, on the fake servo bus only - nothing
    here has run on the real hand, and the contact thresholds are untuned.
    - Hazards 1-4: the Feetech backend no longer enables the torque in its
    constructor; the HAL adopts the first measured pose (not clamped), gives the
    motors torque with that pose as the goal, and sweeps a finger that is outside
    its travel into range instead of snapping it to the edge (also out of passive
    mode); servo_tool scan reports a servo that pings but cannot be read.
    - Contact stop: hal/contact.py (pure) + set_torque_limit on the backend +
    hold_torque and a co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
    [base.py, contact.py, feetech_backend.py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]
2026-09-19 servo_tool calibrate is a window now
    The terminal version (blind j/k jogging in cbreak mode, prompts in between, no
    feedback, no way back) was reported as unusable. calibrate_gui.py: live servo
    positions for all fingers, pick a finger (only that one gets torque, a low
    one), nudge with buttons or the arrow keys, 'This is open', 'It curled IN / It
    opened OUT' after the test twitch, an optional slow test of the whole travel
    that stops pushing when the finger is blocked, Save into hand_params.yaml.
    Only the buttons that make sense in the current step are enabled, and one line
    says what to do next.
    The logic is a tkinter-free Calibrator, tested on moving fake servos: the whole
    flow, a mirrored s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
    [calibrate_gui.py, servo_tool.py, test_calibrate.py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]
2026-09-19 Calibration window: just Set OPEN and Set CLOSED
    Asked for in plain words: no questions, no test twitch, no computed closed
    position. Pick a finger (only that one gets torque, a low one), move it with
    the buttons or the arrow keys, Set OPEN, move it, Set CLOSED, Save. Either
    order, mirrored servos included.
    A span past where the CAD says the linkage binds is warned about in the message
    line and saved anyway: the person at the hand sees the mechanism. Test (slow
    run between the two positions, stops pushing when blocked) stays, as a button
    nobody has to press. closed_step is therefore no longer tied to max_angle -
    noted in the design doc.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
    [calibrate_gui.py, test_calibrate.py, test_feetech.py]
2026-09-19 Real hand from the web console: thumb calibrated, uncalibrated fingers cannot be driven
    - Thumb set on the hand: open 1511, closed 2208 (61 deg of horn). Its max_angle
    is now that travel, so the URDF limit, the HAL's joint states and both 3D
    hands (measured and commanded) show the real horn angle. Saving a finger in
    the calibration window writes its max_angle the same way.
    - servos.<finger>.enabled: false = not calibrated: never torque, never a goal,
    whatever is commanded. index .. pinky are off until they are saved in the
    window (a saved line has no 'enabled: false' any more).
    - Bug from the start-up change, found by driving fake servos through
    hardware.launch.py + rosbridge + t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
    [hand.urdf]
2026-09-19 Docs: mirror teleop spec - controller's browser webcam, MediaPipe and engage logic in the backend
    Replaces the design notes: a second person controls (a head camera would see
    the wearer's free hand and the policy would learn to copy it), the browser only
    streams frames, the recorder reads /hand/command through a new teleoperator.
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2026-09-19 Mirror teleop backend: /ws/mirror tracks the controller's webcam and commands the hand
    MediaPipe HandLandmarker (model in the repo) -> curl -> calibration -> one-euro
    -> engage -> /hand/command, published only on change. One client at a time.
    MOCK=1 tracks a synthetic hand, so the panel needs no webcam and no MediaPipe.
    The status message has 'capturing' and 'error' on top of the spec: the guided
    calibration of the frontend needs them.
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2026-09-19 Mirror teleop: follow a returning hand at once, no match
    Five fingers within 0.15 of the held pose in one frame was too hard to hit on the
    bench, so the frozen mode, the match tolerance and the frame timeout are gone.
    The command can jump after a dropout; the filter and the HAL max_speed soften it.
    The console captures the fist first and the open hand last, so the hand opens
    when the calibration completes instead of closing. Recalibrate restarts the
    guided flow instead of capturing at once. A banner says when no hand is seen.
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2026-09-19 Console: the 3D hand and the mirror view are both always on the page
    With the Mirror switch on, the webcam panel took the 3D hand's place, so
    whoever drove the hand with their own could not see the hand answer. Now the
    main row is 3D hand | mirror | RealSense over iPhone; panels are numbered 01
    hand, 02 mirror, 03 RealSense, 04 iPhone, 05 telemetry.
    - MirrorPanel (replaces MainViewport): MirrorViewport while the switch is on,
    an idle notice while it is off. The webcam and /ws/mirror still exist only
    while the switch is on - an always-visible panel must not become an
    always-on camera that commands the hand.
    - MirrorViewport stacks its bars under the video (it lives in a tall, narrow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
2026-09-19 Contact stop: the motor current is the first blocked signal, 100 mA
    The encoder rule never stopped a finger that met something closer than
    blocked_error to its target, or that crept into something soft. The HAL now
    reads position..current in one sync read and a finger is blocked when its
    current stays at or above blocked_current for current_cycles cycles; the
    encoder rule stays as the fallback. 100 mA was found on the hand with
    servo_tool probe, which got --stop-current to try a threshold, and whose hold
    phase no longer drives on to closed after a stop.
    hand_params.yaml also carries the calibration of all five fingers and
    torque_limit 600 as run on the hand. Known: ring and pinky closed_ste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
    [base.py, contact.py, feetech_backend.py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]
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2026-09-19 Contact stop: summed excess current instead of cycles in a row
    "5 cycles at or above 100 mA" let a hard contact push at the full torque
    limit for 0.1 s, and plastic broke on the hand. Now the mA above
    blocked_current are summed (a cycle below it takes its shortfall off) and
    blocked_excess (150) is the block: one huge cycle blocks at once, a small
    overload after some cycles, the peak of a free start drains away. Replayed on
    the logs from the hand: the push against the middle finger blocks 2 cycles
    earlier, its free start (34) does not. servo_tool probe --stop-current uses
    the same rule (--stop-excess).
    [contact.py, hal_node.py, servo_tool.py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]
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2026-09-20 Camera streams drop frames for a slow page; detector capped; bridge reconnects
    A websocket's send buffer is unbounded, so a browser that painted slower
    than the camera ran watched a growing backlog of old frames (minutes on a
    busy laptop). The page now says "ready" per frame and the backend sends
    the newest frame only after it; a client that never says it is served as
    before. The YOLO detector took every core (uvicorn at 700 %): DETECT_HZ
    (4) and DETECT_THREADS (2) cap it. The RealSense bridge restarts its
    pipeline when the camera drops off the bus instead of dying, and the rate
    meter no longer divides by zero when two messages share a clock tick.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
2026-09-20 Console: the iPhone comes from ROS, the Record3D client is gone
    The phone now belongs to iphone_camera_node, so the backend is a pure
    consumer of ROS again: it subscribes /head_camera/color/image_raw/compressed
    and passes the JPEG through to WS /ws/camera/iphone/color untouched. Deleted:
    the Record3D USB / Wi-Fi client and its worker, /api/iphone, the rotation
    setting (the node fixes rotation and size: they are part of the dataset), the
    iPhone depth stream, the phone address card and the rotate button. record3d
    and aiortc leave requirements.txt. The panel with no frames says to start
    head_camera:=iphone and read the node log.
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2026-09-20 Camera panels: the luma histogram no longer reads the canvas back
    Twice a second per colour panel it copied the GPU-backed stream canvas into a
    software canvas: a synchronous readback that holds the page's main thread until
    the GPU has finished everything queued, the 3D hand included - and with it the
    mirror overlay, which is drawn from that thread. In a profile of the page it
    was the largest item by far. The histogram now decodes a 64 x 48 copy of the
    newest JPEG off the main thread.
2026-09-20 Ring and pinky open past the CAD pose: min_angle below zero, both linkage solvers follow
    Their calibrated travel (101 and 96 deg of horn) is more than fits between the
    CAD pose and where the linkage binds, so with open = the CAD pose
    linkage_publisher refused to start and the web viewer froze the links while the
    horn turned on: two fingers pointing straight down. The fingers work on the
    hand, so they open past the CAD pose; min_angle says by how much (estimates:
    ring centred between its binds, pinky closing at closed_rad). The Python and
    the TypeScript solver build their table over [min_angle, max_angle] out from
    the CAD pose both ways, the publisher checks the open bind too, the ghost and
    t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
    [hand.urdf]
2026-09-20 Hand orientation from the wrist camera's IMU: /hand/orientation
    camera.launch.py turns the D435i's gyro and accelerometer on (one /camera/imu)
    and starts hand_orientation_node: a complementary filter (gyro integrated, tilt
    pulled to gravity, gyro bias learnt while the hand lies still), samples turned
    into base_link with camera.rpy. No magnetometer, so yaw is relative to the
    start or to the last /hand/reset_yaw. With a camera that has no IMU it
    publishes nothing. Also in next-work: ring and pinky travel too far, the ring
    to within 8 deg of a bind at both ends.
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2026-09-20 Remove the hand orientation from the RealSense IMU
    The camera on the hand is a D435, which has no IMU, and the feature is not
    wanted: hand_orientation_node, the filter and its tests, the IMU streams and
    the node in camera.launch.py, /hand/orientation in the contract, the backend's
    orientation handling and the stable-frame object tracker, and the viewer's yaw
    are gone. The object tracker is the camera-frame one again, with the short
    memory and DETECT_LABELS of the last change.
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2026-09-20 Hand view: no ground grid, fainter range rings, and a camera that stays put
    The 10 mm grid cluttered the floor next to the rings; the contact shadow
    and the rings are enough. Rings and ticks drop to ~0.35 opacity. The idle
    orbit is off on every preset and the first objects no longer switch the
    view to chase: the camera moves only when the user picks a preset or drags.
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2026-09-20 Console layout: the 3D hand is the page; command block under it, cameras in a column
    The hand panel takes ~70 % of the width and the full height; the command
    block (sliders, Arm / Backdrive / Mirror, presets) sits in a short strip
    under it; mirror, RealSense and iPhone stack on the right. The per-finger
    telemetry columns and their sparkline history are gone: the fingertip
    labels and the command block's measured ticks already show those numbers.
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2026-09-20 Console: the command block is one compact row, its strip under the hand as low as it needs
    On top of the layout of c115c3c (the hand is the page, the command panel under
    it, cameras in a column), which stays as it is: the command block's switches,
    presets and finger sliders are laid out in a wrapping row with horizontal
    sliders (the tick under a slider is the measured position) instead of a column
    of vertical sliders, and the strip takes the block's height instead of a fixed
    10.5rem. On a 1000 px screen the strip goes from 168 to about 100 px and the
    3D hand gets the rest.
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2026-09-20 Faster fingers: HAL max_speed 4.0 / max_accel 60, servo ramp at its most; hot cross buns' quick notes are strokes
    The HAL's defaults go from 2.0 / 20 to 4.0 / 60 (a full close in ~0.3 s instead
    of ~0.6), in the node and in both launch files; the sim's joint velocity limit
    goes to 6 rad/s so that it does not cap that. The servos' own acceleration
    register goes from 50 to 254: at 50 a servo took another 0.3 s to reach its
    speed and coasted as long past a goal that stopped, which turned a quick key
    stroke into a wobble. servos.torque_limit is NOT changed: it is the duty cap,
    so it is also what the real servos' top speed hangs on (~1.8 travels/s measured
    at 600) and the force of everything a fin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
    [feetech_backend.py, hal_node.py, test_contact.py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]
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2026-09-20 Lambda training: launch, file-only watchdog, held-out evaluation, agent skill
    Implements docs/specs/lambda-training-design.md, so a SmolVLA fine-tune can run
    on a rented GPU with no person at the keyboard and cannot bill without limit.
    - policy/lambda/: launch, setup, pull, watchdog, terminate and check scripts,
    cut down from the altrux scripts. The watchdog reads only marker files (no
    process detection) and enforces the cap from .rental; run_logged.sh is the
    second writer of .watchdog-alive and stops its touches on a silent log.
    - heldout.py: seeded episode split and the action error of a checkpoint, as
    lerobot-train has no validation split. synth_dataset.py: a fake dataset with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
2026-09-20 Movements: the next pose is never sent before the hand has arrived at the last one
    A step of a movement is over when its seconds have passed AND every finger is
    measured within 0.04 of the pose that was sent. On slow motors the quick notes
    of a tune were cut short: the next pose went out on the clock, the finger
    turned around wherever it was. Now slow motors stretch the tempo and every
    stroke is finished. A finger that cannot arrive (something in its way, torque
    off, ROS down) holds the movement for 3 s at most, then it goes on; the status
    has `waiting` and counts those steps in `not_arrived`, and the page shows both.
    The MCP server's move_hand waits for the arrival in the same way and repor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
2026-09-20 RealSense picture portrait: turned 90 deg clockwise on the page and for the detector
    The wrist camera sits portrait on the hand, so its picture lay on its side.
    REALSENSE_ROTATION (default 90) turns the colour and the depth panel on the
    page (the frames still arrive as sent; the meta carries the rotation and the
    hook swaps the sides) and the picture the object detector gets - it knows
    upright bottles - with its boxes put back into the picture as sent, where the
    depth and the intrinsics live. The ROS topics, the recordings and the policy
    keep the camera's own orientation: a recorded dataset does not change.
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2026-09-20 setup.sh: torch build for the driver's CUDA; the scripts smoke asks for the terminate on any failure
    The first rental failed: uv installed the cu130 wheel and the Lambda image
    has a CUDA 12.8 driver, so torch saw no GPU. --torch-backend=auto picks the
    build for the driver (cu129 there). The failure was before the smoke level's
    exit trap, so the instance did not ask for its terminate: the trap is now the
    first thing. Verified on that instance: --smoke-scripts passed end to end.
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2026-09-20 Spec: the contact stop uses the current only
    The encoder rule (far from the setpoint and not moving) goes: it made the false
    stops of 4ccee1a, and a hard stall shows in the current sooner. The encoder
    still releases a blocked finger.
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2026-09-20 Movements: both tunes press half as deep (PRESS 0.5, quick notes 0.25)
    The whole travel bent the fingers too far for a key press.
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
